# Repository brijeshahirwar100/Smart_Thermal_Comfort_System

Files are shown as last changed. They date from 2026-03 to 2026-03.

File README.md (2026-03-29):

# 🌡️ Smart Thermal Comfort System

<p align="center">
  
  
  
  
  
 
</p>

---

## 📋 Table of Contents

- [Overview](#-overview)
- [Features](#-features)
- [System Architecture](#-system-architecture)
- [Hardware Components](#-hardware-components)
- [Pin Configuration](#-pin-configuration)
- [TCI Formula](#-tci-formula)
- [Firmware Structure](#-firmware-structure)
- [Libraries Required](#-libraries-required)
- [Setup & Installation](#-setup--installation)
- [IoT Dashboard (ThingsBoard)](#-iot-dashboard-thingsboard)
- [PCB Design](#-pcb-design)
- [Simulation Results](#-simulation-results)
- [Project Structure](#-project-structure)

---

## 🔍 Overview

The **Smart Thermal Comfort System** is an ESP32-based embedded system that provides **personalized thermal comfort** by computing a real-time **Thermal Comfort Index (TCI)** from multi-sensor fusion data. Unlike conventional thermostat systems that rely solely on ambient temperature, this system combines:

- **Ambient temperature & humidity** (DHT22)
- **Skin/surface temperature** (DS18B20)
- **Presence detection** (VL53L0X / digital presence pin)

Based on the computed TCI, the system automatically controls a **cooling fan** (TC647 driver) and a **Peltier thermoelectric module** (BTS7960 H-bridge driver) to maintain optimal thermal comfort. All sensor data and actuator states are published in real-time to a **ThingsBoard IoT dashboard** over **Wi-Fi + MQTT**.

---

## ✨ Features

| Feature | Description |
|---|---|
| 🧠 **TCI Computation** | Personalized Thermal Comfort Index from skin temp, ambient temp & humidity |
| 👁️ **Presence Detection** | System activates only when user is detected — saves energy |
| 🤖 **AUTO Mode** | TCI-based autonomous control of fan and Peltier module |
| 🕹️ **MANUAL Mode** | User override via physical buttons or IoT dashboard |
| 📡 **IoT Dashboard** | Real-time monitoring & control via ThingsBoard + MQTT |
| 🔁 **RPC Control** | Remote setMode, setFan, setPeltier commands from dashboard |
| 📟 **Serial Debug** | 5-second periodic debug prints over Serial (9600 baud) |
| ⚡ **Dual Power Rails** | 12V input → LM2596SX Buck Converter → 5V & 3.3V regulated |
| 🖥️ **Custom PCB** | 2-layer compact PCB (107.4 × 30.975 mm) designed in Altium Designer |

---

## 🏗️ System Architecture

<p align="center">
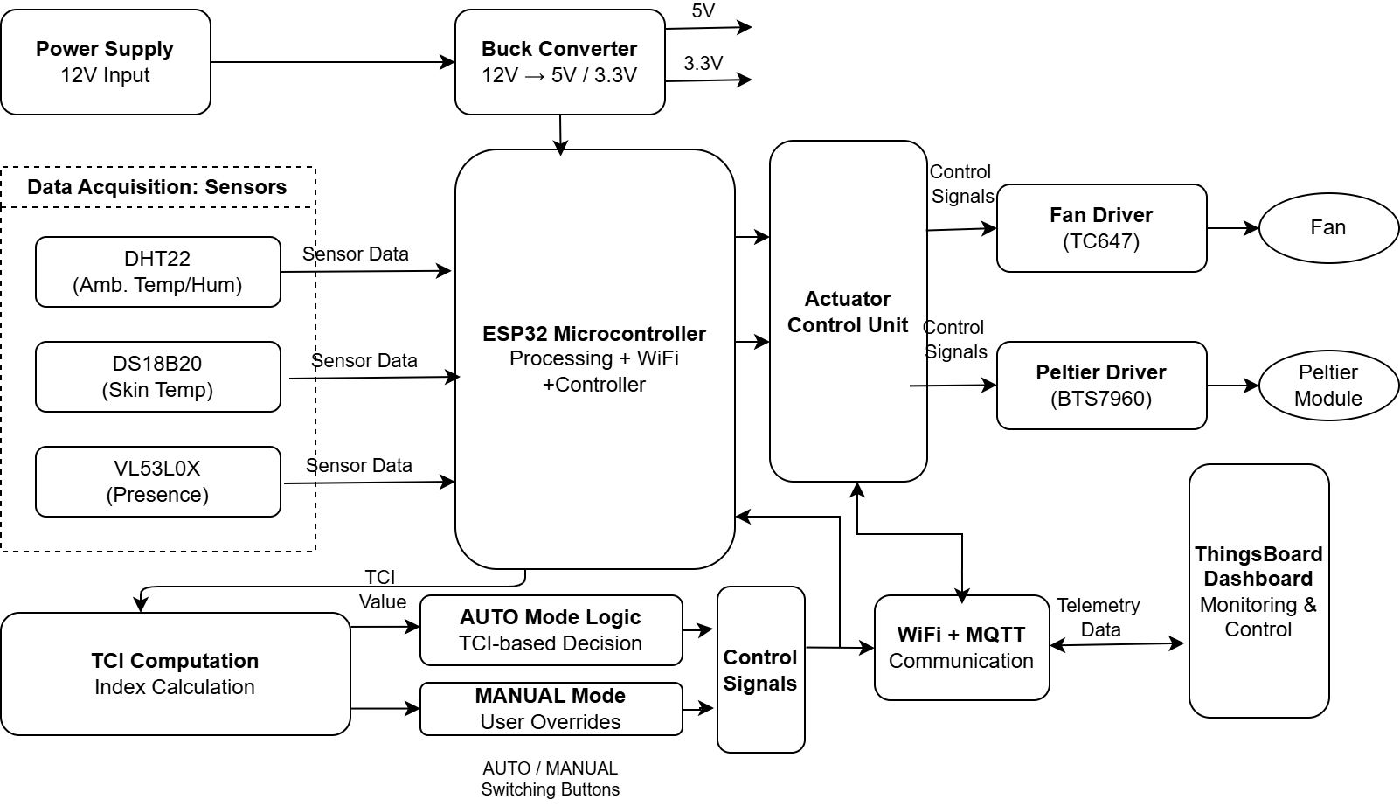
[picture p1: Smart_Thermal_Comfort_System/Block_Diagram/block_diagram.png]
System Block Diagram
  
</p>

**Control Logic (AUTO Mode):**
```
TCI > +2  →  Fan ON,     Peltier OFF   (Too Hot — Cool Down)
TCI < -2  →  Fan OFF,    Peltier ON    (Too Cold — Heat Up)
-2 ≤ TCI ≤ +2  →  Fan OFF, Peltier OFF  (Comfortable Zone)
Presence = FALSE  →  Fan OFF, Peltier OFF  (No one present)
```

---

## 🔧 Hardware Components

| Component | Part Number | Function | Interface |
|---|---|---|---|
| **Microcontroller** | ESP32-WROOM-32E (16MB) | Main processing, WiFi, control | — |
| **Ambient Sensor** | DHT22 | Temperature (−40 to 80°C) & Humidity (0–100%) | Digital (GPIO2) |
| **Skin Temp Sensor** | DS18B20 | Surface/skin temperature, ±0.5°C | 1-Wire (GPIO7) |
| **Presence Sensor** | VL53L0X / Digital | User presence detection | Digital (GPIO3) |
| **Fan Driver** | TC647BEUATR | PWM-controlled fan driver | PWM (GPIO5) |
| **Peltier Driver** | BTS7960B | H-bridge Peltier driver, 12V/43A | Digital (GPIO6) |
| **Buck Converter** | LM2596SX-ADJ | 12V → 5V & 3.3V regulation | — |
| **Rectifier Diode** | SS54B | Flyback protection | — |
| **Ethernet Module** | W5500 | Network connectivity (simulation) | SPI |
| **Cool Button** | Tactile Switch | Manual cooling trigger | Digital (GPIO4) |
| **Heat Button** | Tactile Switch | Manual heating trigger | Digital (GPIO8) |

---

## 📌 Pin Configuration

```
ESP32 / Arduino Pin Map
──────────────────────────────────────
Pin 2  → DHT22 Data          (Ambient Temp/Humidity)
Pin 3  → Presence Input      (VL53L0X / Digital)
Pin 4  → Button COOL         (Manual Cool — INPUT)
Pin 5  → Fan PWM Output      (TC647 Fan Driver)
Pin 6  → Peltier Output      (BTS7960 H-Bridge)
Pin 7  → DS18B20 Data        (Skin Temp, 1-Wire)
Pin 8  → Button HEAT         (Manual Heat — INPUT)

SPI (W5500 Ethernet for simulation):
Pin 10 → CS
Pin 11 → MOSI
Pin 12 → MISO
Pin 13 → SCK
──────────────────────────────────────
```

---

## 📐 TCI Formula

The **Thermal Comfort Index (TCI)** is computed as:

```
TCI = (skinTemp − 34.0) + 0.5 × (ambientTemp − 24.0) + 1.5 × (humidity / 100.0)
```

| Variable | Description | Baseline |
|---|---|---|
| `skinTemp` | DS18B20 skin/surface temperature (°C) | 34.0°C (neutral skin temp) |
| `ambientTemp` | DHT22 ambient temperature (°C) | 24.0°C (neutral ambient) |
| `humidity` | DHT22 relative humidity (%) | Normalized as fraction |

**Interpretation:**
- **TCI > +2** → Too Hot → Fan ON
- **TCI < −2** → Too Cold → Peltier ON (heating)
- **−2 ≤ TCI ≤ +2** → Comfortable → All actuators OFF

---

## 📁 Firmware Structure

The firmware is written in **Arduino C++** with a modular multi-file architecture:

```
Firmware/
├── Smart_thermal_comfort_system.ino   ← Main entry point (setup + loop)
├── config.h                           ← All pin definitions, MQTT config, timing
├── sensor.h / sensor.cpp              ← DHT22, DS18B20, presence, TCI computation
├── actuators.h / actuators.cpp        ← Fan & Peltier control, AUTO/MANUAL logic
├── network.h / network.cpp            ← MQTT connect, RPC callback, reconnect
├── telemetry.h / telemetry.cpp        ← Periodic JSON telemetry publish to MQTT
└── debug.h / debug.cpp                ← Serial debug print (every 5 seconds)
```

**Main Loop Flow:**
```
loop()
 ├── sensor_update()     → Read DHT22, DS18B20, presence, buttons
 ├── actuator_update()   → Evaluate TCI / manual buttons, drive outputs
 ├── network_loop()      → MQTT keep-alive, reconnect if needed
 ├── telemetry_send()    → Publish JSON to ThingsBoard every 2 seconds
 └── debug_print()       → Serial monitor output every 5 seconds
```

---

## 📚 Libraries Required

Install these via **Arduino IDE → Library Manager** or **PlatformIO**:

| Library | Install Name | Purpose |
|---|---|---|
| DHT sensor library | `DHT sensor library` by Adafruit | DHT22 temperature & humidity |
| Adafruit Unified Sensor | `Adafruit Unified Sensor` | Dependency for DHT |
| OneWire | `OneWire` by Paul Stoffregen | 1-Wire bus for DS18B20 |
| DallasTemperature | `DallasTemperature` by Miles Burton | DS18B20 temperature reading |
| PubSubClient | `PubSubClient` by Nick O'Leary | MQTT client |
| Ethernet | `Ethernet` (built-in) | W5500 Ethernet (simulation) |

---

## ⚙️ Setup & Installation

### 1. Clone the Repository
```bash
git clone https://github.com/brijeshahirwar100/Smart_Thermal_Comfort_System.git
cd Smart-Thermal-Comfort-System
```

### 2. Configure Credentials
Open `Firmware/config.h` and update:

```cpp
// ── MQTT ──────────────────────────────────────────
#define MQTT_SERVER  "mqtt.thingsboard.cloud"
#define TOKEN        "YOUR_THINGSBOARD_DEVICE_TOKEN"   // ← Replace this

// ── SENSOR PINS ───────────────────────────────────
#define DHT_PIN      2
#define DHT_TYPE     DHT22
#define DS18_PIN     7

// ── INPUT PINS ────────────────────────────────────
#define PRESENCE_PIN 3
#define BTN_COOL     4
#define BTN_HEAT     8

// ── OUTPUT PINS ───────────────────────────────────
#define FAN_PIN      5
#define PELTIER_PIN  6

// ── TIMING ────────────────────────────────────────
#define TELEMETRY_INTERVAL 2000   // ms
```

### 3. Install Libraries
In Arduino IDE: **Tools → Manage Libraries** and install all libraries listed above.

### 4. Select Board & Upload
- Board: **ESP32 Dev Module** (or Arduino Uno for simulation)
- Port: Select your COM port
- Upload Speed: 115200
- Click **Upload**

### 5. Monitor Serial Output
Open **Serial Monitor** at **9600 baud**. You should see:
```
.MQTT connected
====================================
Ambient: 14.60 C
Humidity: 44.50 %
Skin:     13.38 C
TCI:      13.87
Presence: DETECTED
Mode: AUTO
Fan:      OFF
Peltier:  ON
Cool btn: RELEASED
Heat btn: RELEASED
====================================
```

---

## 📊 IoT Dashboard (ThingsBoard)

<p align="center">
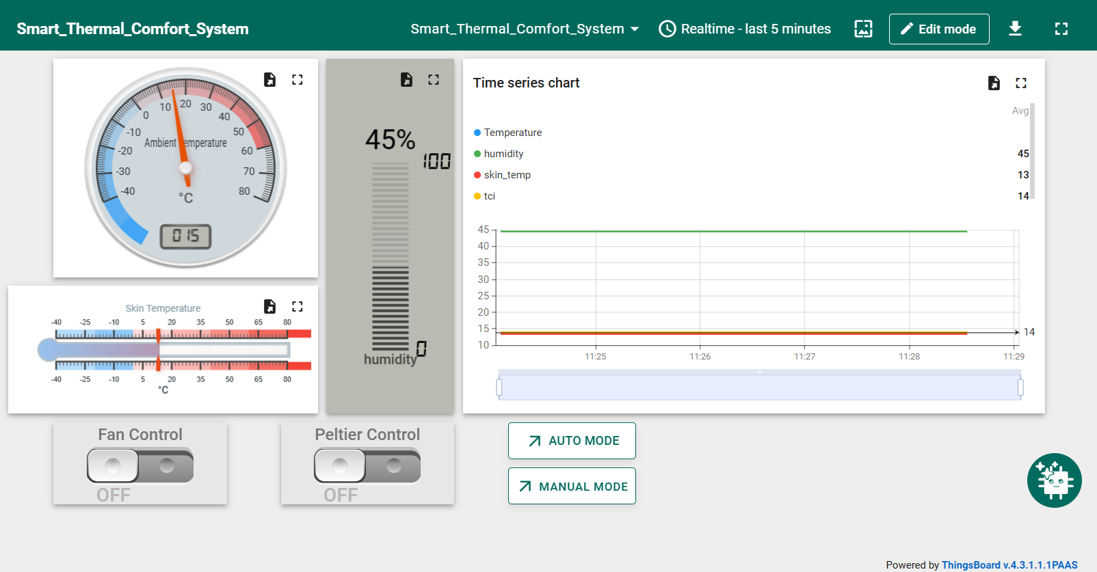
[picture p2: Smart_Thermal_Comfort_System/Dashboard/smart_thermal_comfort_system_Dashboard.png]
ThingsBoard Dashboard
  
</p>

### Dashboard Widgets
| Widget | Data Key | Description |
|---|---|---|
| Analog Gauge | `ambient_temp` | Real-time ambient temperature |
| Horizontal Slider | `skin_temp` | Real-time skin temperature |
| Vertical Bar | `humidity` | Real-time relative humidity |
| Time-Series Chart | `ambient_temp`, `humidity`, `skin_temp`, `tci` | Historical trend graph |
| Toggle Switch | `setFan` RPC | Manual fan ON/OFF |
| Toggle Switch | `setPeltier` RPC | Manual Peltier ON/OFF |
| Button | `setMode: AUTO` | Switch to AUTO TCI mode |
| Button | `setMode: MANUAL` | Switch to MANUAL override mode |

### MQTT Topics
| Topic | Direction | Description |
|---|---|---|
| `v1/devices/me/telemetry` | Publish | Sensor data & actuator states |
| `v1/devices/me/rpc/request/+` | Subscribe | Receive commands from dashboard |
| `v1/devices/me/rpc/response/{id}` | Publish | Acknowledge RPC commands |

### Setup ThingsBoard
1. Create a free account at [thingsboard.cloud](https://thingsboard.cloud)
2. Add a new **Device**
3. Copy the **Device Access Token**
4. Paste it into `config.h` as `TOKEN`
5. Create a dashboard and add widgets for the keys above

---

## 🖥️ PCB Design

Designed in **Altium Designer** — 2-layer compact PCB.

### PCB Specifications
| Parameter | Value |
|---|---|
| Board Size | 107.4 × 30.975 mm |
| Layers | 2 (Top + Bottom copper) |
| Design Tool | Altium Designer |

### PCB Images

### Schematic
<p align="center">
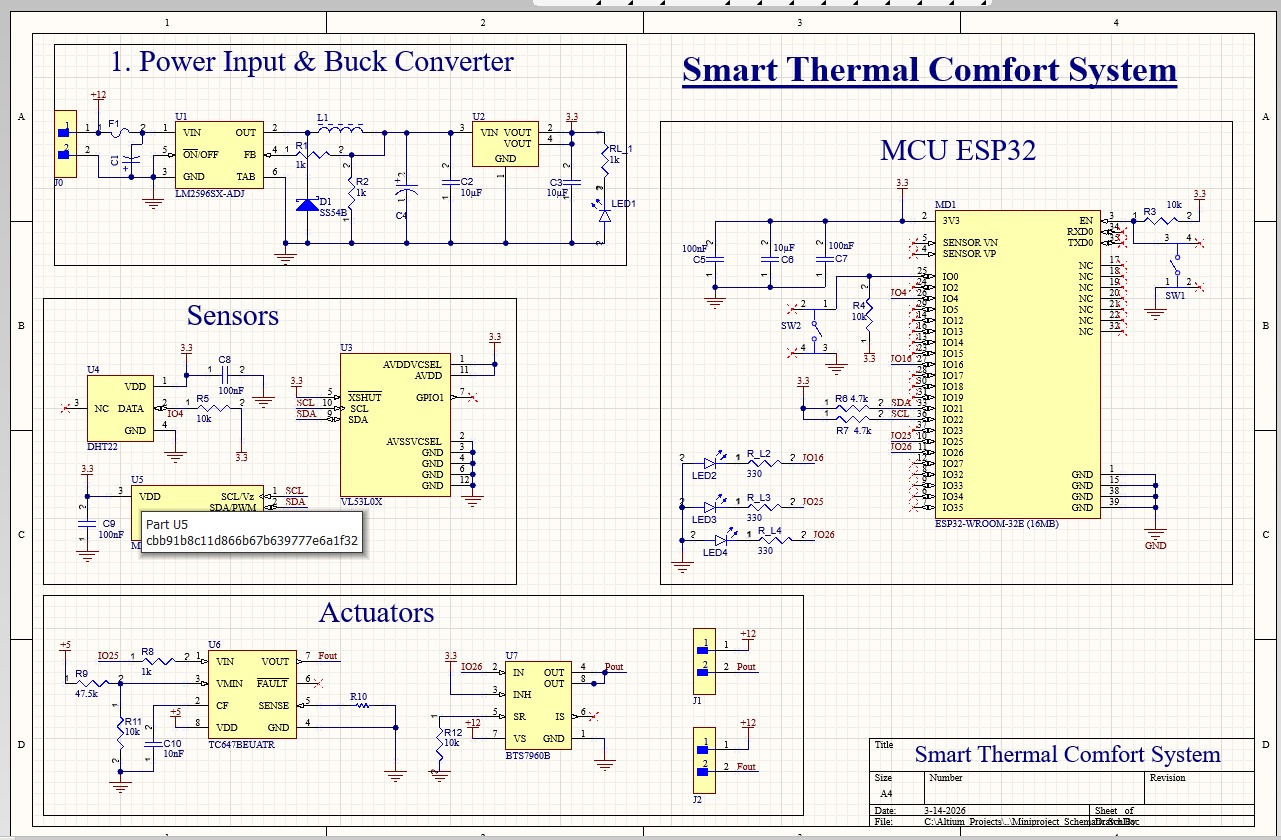
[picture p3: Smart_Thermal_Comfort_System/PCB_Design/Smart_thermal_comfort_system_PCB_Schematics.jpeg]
PCB Schematic
  
</p>

**Schematic Sections:**
1. **Power Input & Buck Converter** — LM2596SX-ADJ, SS54B diode, filter capacitors
2. **MCU** — ESP32-WROOM-32E (16MB), decoupling caps, mode select switch
3. **Sensors** — DHT22, VL53L0X (I2C with XSHUT), DS18B20 (1-Wire)
4. **Actuators** — TC647BEUATR (fan driver), BTS7960B (Peltier H-bridge)

### 2D Layout 
<p align="center">
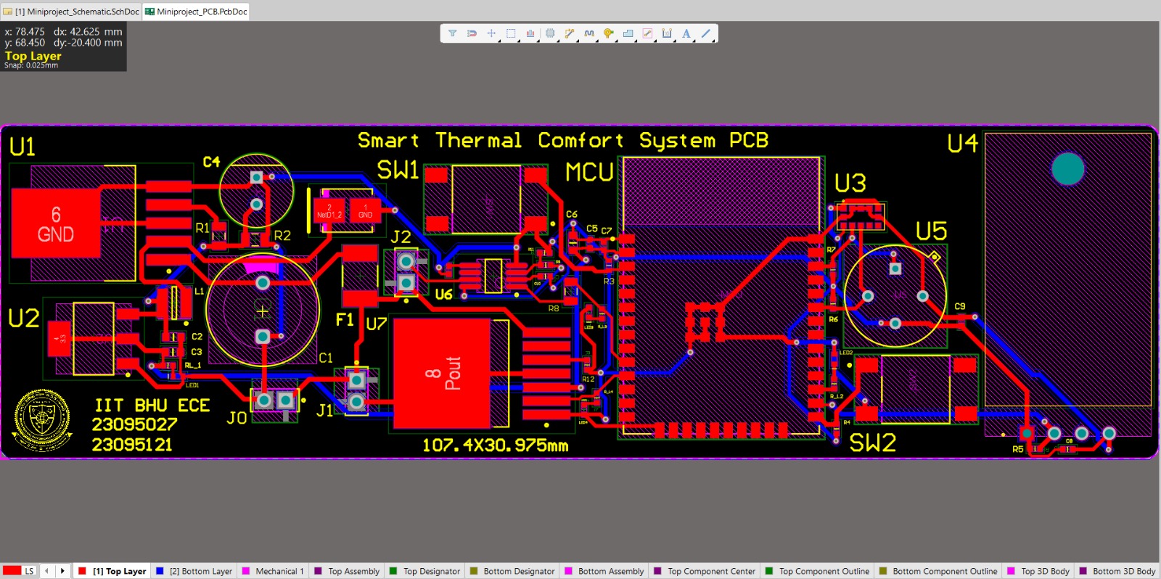
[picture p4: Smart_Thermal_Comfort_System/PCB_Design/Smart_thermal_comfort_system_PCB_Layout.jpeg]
PCB 2D layout
  
</p>

### 3D Layout 
<p align="center">
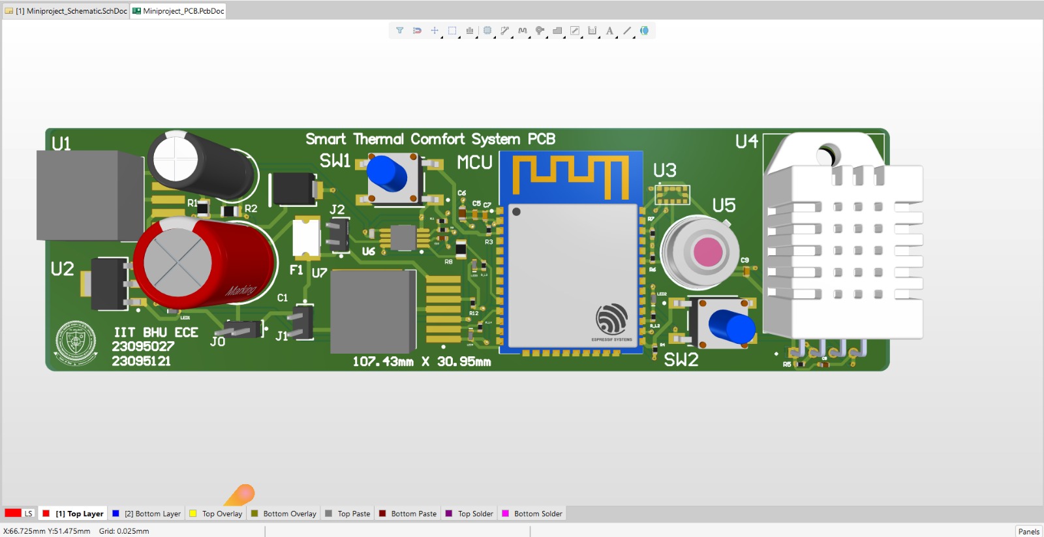
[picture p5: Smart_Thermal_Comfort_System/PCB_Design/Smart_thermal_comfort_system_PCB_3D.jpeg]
PCB 3D layout
  
</p>

### Gerber Files
Production-ready Gerber files are available in [`PCB_Design/Gerber/`](PCB_Design/Gerber/).

| File | Layer |
|---|---|
| `PCB1_Copper_Signal_Top.gbr` | Top copper layer |
| `PCB1_Copper_Signal_Bot.gbr` | Bottom copper layer |
| `PCB1_Soldermask_Top.gbr` | Top soldermask |
| `PCB1_Soldermask_Bot.gbr` | Bottom soldermask |
| `PCB1_Legend_Top.gbr` | Top silkscreen |
| `PCB1_PTH_Drill.gbr` | Plated through-hole drills |
| `PCB1_NPTH_Drill.gbr` | Non-plated drills |
| `PCB1_Profile.gbr` | Board outline |

---

## 🧪 Simulation Results

Simulated in **PICSimLab** with virtual DHT22, DS18B20, W5500 Ethernet, and MQTT broker.

<p align="center">
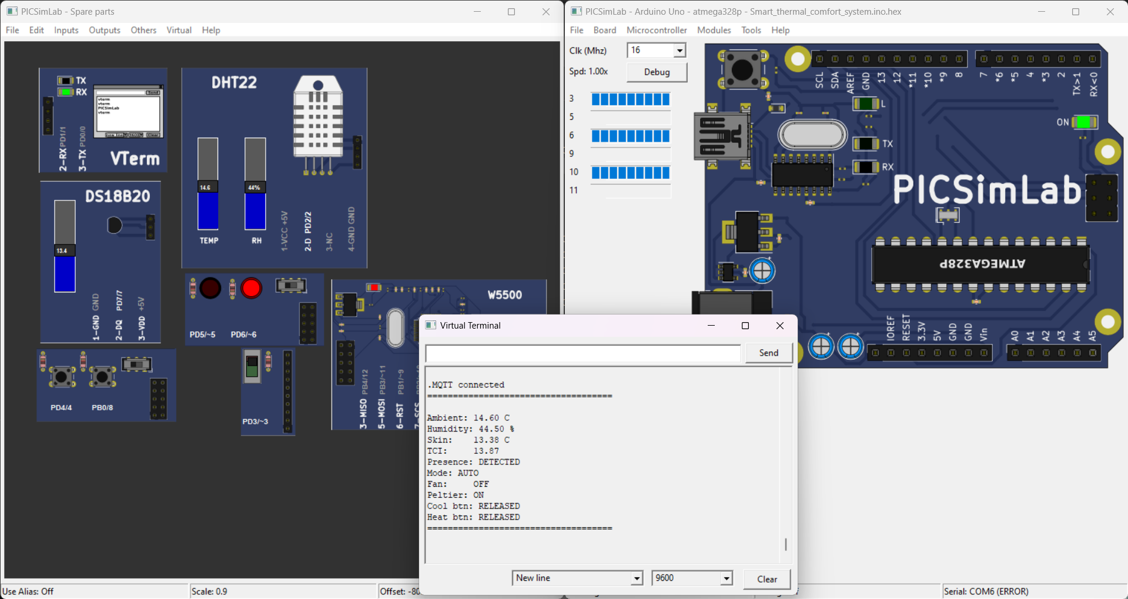
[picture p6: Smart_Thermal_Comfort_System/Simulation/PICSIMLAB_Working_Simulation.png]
PICSimLab Simulation
  
</p>

### Simulation Output (Virtual Terminal)
```
.MQTT connected
====================================
Ambient: 14.60 C
Humidity: 44.50 %
Skin:     13.38 C
TCI:      13.87
Presence: DETECTED
Mode: AUTO
Fan:      OFF
Peltier:  ON
Cool btn: RELEASED
Heat btn: RELEASED
====================================
```

**Verification:** With TCI = 13.87 (well below −2 threshold... wait — the formula gives negative here):
```
TCI = (13.38 − 34.0) + 0.5 × (14.60 − 24.0) + 1.5 × (44.50/100)
    = (−20.62) + 0.5 × (−9.40) + 1.5 × 0.445
    = −20.62 − 4.70 + 0.6675
    = −24.65  →  TCI << −2  →  Peltier ON ✓
```
**Result confirmed:** AUTO mode correctly activates **Peltier (heating)** when TCI is far below comfort zone. ✅

---

## 📂 Project Structure

```
Smart-Thermal-Comfort-System/
│
├── README.md
│
├── Firmware/
│   ├── Smart_thermal_comfort_system.ino
│   ├── config.h
│   ├── sensor.h
│   ├── sensor.cpp
│   ├── actuators.h
│   ├── actuators.cpp
│   ├── network.h
│   ├── network.cpp
│   ├── telemetry.h
│   ├── telemetry.cpp
│   ├── debug.h
│   └── debug.cpp
│
├── PCB_Design/
│   ├── Smart_thermal_comfort_system_PCB_Schematics.jpeg
│   ├── Smart_thermal_comfort_system_PCB_Layout.jpeg
│   ├── Smart_thermal_comfort_system_PCB_3D.jpeg
│   └── Gerber/
│       ├── PCB1_Copper_Signal_Top.gbr
│       ├── PCB1_Copper_Signal_Bot.gbr
│       ├── PCB1_Soldermask_Top.gbr
│       ├── PCB1_Soldermask_Bot.gbr
│       ├── PCB1_Legend_Top.gbr
│       ├── PCB1_Legend_Bot.gbr
│       ├── PCB1_PTH_Drill.gbr
│       ├── PCB1_NPTH_Drill.gbr
│       ├── PCB1_Profile.gbr
│       └── PCB1.apr
│
├── Block_Diagram/
│   └── block_diagram.png
│
├── Simulation/
│   └── PICSIMLAB_Working_Simulation.png
│
├── Dashboard/
│   └── smart_thermal_comfort_system_Dashboard.png
│
└── Presentation/
    └── MINI_PROJECT_EC-323_EMBEDDED_SYSTEM_DESIGN.pptx
```

---

##  Owner

**Brijesh Ahirwar**
B.Tech, Electronics & Communication Engineering
IIT (BHU) Varanasi

---

## 📄 License

This project is licensed under the **MIT License** — feel free to use,
modify, and distribute with proper credit to the original authors.

---

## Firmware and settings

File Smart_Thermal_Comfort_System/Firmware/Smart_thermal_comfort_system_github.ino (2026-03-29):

#include "config.h"
#include "sensor.h"
#include "actuators.h"
#include "network.h"
#include "telemetry.h"
#include "debug.h"

static unsigned long lastDebug = 0;

void setup() {
    Serial.begin(9600);
    sensor_begin();
    actuator_begin();
    network_begin();
}

void loop() {
    sensor_update();
    actuator_update();
    network_loop();
    telemetry_send();

    if (millis() - lastDebug > 5000) {
        lastDebug = millis();
        debug_print();
    }
}

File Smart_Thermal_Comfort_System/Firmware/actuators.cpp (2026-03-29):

#include <Arduino.h>
#include "actuators.h"
#include "sensor.h"
#include "config.h"

// ── GLOBALS ───────────────────────────────────────
String systemMode   = "AUTO";
bool   fanState     = false;
bool   peltierState = false;

// ── INIT ──────────────────────────────────────────
void actuator_begin() {
    pinMode(FAN_PIN,     OUTPUT);
    pinMode(PELTIER_PIN, OUTPUT);
}

// ── APPLY ─────────────────────────────────────────
static void applyOutputs() {
    digitalWrite  (FAN_PIN,     fanState     ? HIGH : LOW);   // FIX: was HIGH(=1) in AUTO mode
    digitalWrite (PELTIER_PIN, peltierState ? HIGH : LOW);
}

// ── UPDATE ────────────────────────────────────────
void actuator_update() {

    // Presence off → everything off
    if (!sensor_getPresence()) {
        fanState = peltierState = false;
        applyOutputs();
        return;
    }

    // Manual mode: outputs already set by sensor_update() buttons
    if (systemMode == "MANUAL") {
        applyOutputs();
        return;
    }

    // Auto mode: TCI-based control
    float tci = sensor_getTCI();

    if      (tci > 2) { fanState = true;  peltierState = false; }
    else if (tci < -2) { fanState = false; peltierState = true;  }
    else               { fanState = false; peltierState = false; }

    applyOutputs();
}

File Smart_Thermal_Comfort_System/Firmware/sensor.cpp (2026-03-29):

#include <Arduino.h>
#include <DHT.h>
#include <OneWire.h>
#include <DallasTemperature.h>

#include "config.h"
#include "sensor.h"
#include "actuators.h"

// ── HARDWARE ──────────────────────────────────────
static DHT             dht(DHT_PIN, DHT_TYPE);
static OneWire         oneWire(DS18_PIN);
static DallasTemperature ds18(&oneWire);

// ── STATE ─────────────────────────────────────────
static float ambientTemp = 0.0;
static float humidity    = 0.0;
static float skinTemp    = 30.0;
static bool  presence    = false;

// ── INIT ──────────────────────────────────────────
void sensor_begin() {
    dht.begin();
    ds18.begin();
    pinMode(PRESENCE_PIN, INPUT);
    pinMode(BTN_COOL, INPUT);
    pinMode(BTN_HEAT, INPUT);
}

// ── UPDATE ────────────────────────────────────────
void sensor_update() {
    // DHT22
    float t = dht.readTemperature();
    float h = dht.readHumidity();
    if (!isnan(t)) ambientTemp = t;
    if (!isnan(h)) humidity    = h;

    // DS18B20
    ds18.requestTemperatures();
    float ds = ds18.getTempCByIndex(0);
    skinTemp = (ds != DEVICE_DISCONNECTED_C) ? ds : 30.0;

    // Presence
    presence = (digitalRead(PRESENCE_PIN) == HIGH);

    // Buttons — only act in MANUAL mode
    if (systemMode == "MANUAL") {
        if (digitalRead(BTN_COOL) == HIGH) {
            fanState = true;  peltierState = false;
        } else if (digitalRead(BTN_HEAT) == HIGH) {
            fanState = false; peltierState = true;
        }
    }
}

// ── GETTERS ───────────────────────────────────────
float sensor_getAmbient()  { return ambientTemp; }
float sensor_getHumidity() { return humidity; }
float sensor_getSkin()     { return skinTemp; }
bool  sensor_getPresence() { return presence; }

// TCI in one place — FIX: was duplicated in 3 files
// Formula: weighted skin + ambient only (humidity normalised included — different unit)
float sensor_getTCI() {
    return   (skinTemp-34.0 ) + 0.5 *( ambientTemp-24.0) + 1.5 * (humidity/100.0);


 
}
